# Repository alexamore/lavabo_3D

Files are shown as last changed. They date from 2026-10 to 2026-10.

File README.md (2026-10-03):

# Fontanella d'angolo per riempimento bottiglie — stampabile in 3D (ASA, Bambu Lab P2S)

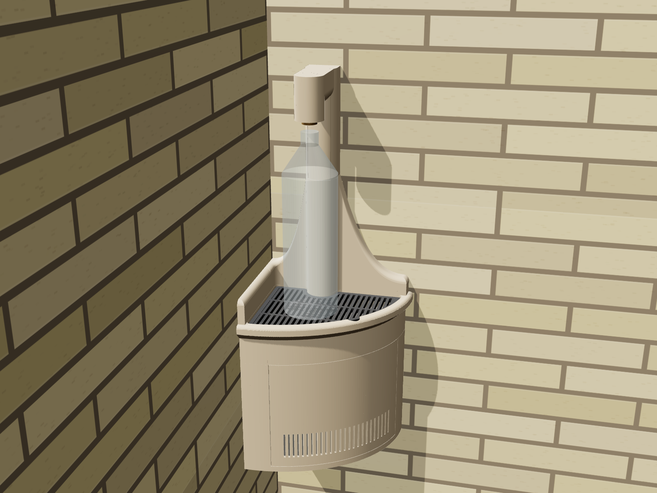
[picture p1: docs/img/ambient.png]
Vista ambientata


Piccola fontanella da esterno da fissare nell'angolo interno di due pareti in mattoni. Serve solo a
riempire bottiglie. La pianta ha **esattamente tre lati**: **250 mm** lungo la parete B, la parete
lunga su cui si fissa la fontana; **200 mm** lungo la parete A, la parete corta. Entrambi partono
dall'angolo e sono chiusi da un bordo frontale curvo e affusolato.
Il tubo PPR **esce già dal muro** della parete da 25 cm, con il centro **a 95 mm dall'angolo**
(l'angolo è a sinistra guardando la parete). Non c'è nessun tubo che arriva dal basso.
Sotto il piano c'è un vano tecnico con serbatoio estraibile, pompa sommersa 12 V, galleggianti e un
box stagno per l'ESP32.

Tutta la geometria è **parametrica** (`cad/params.py`) e viene generata da `cad/fontanella.py`.
Ogni pezzo stampato sta entro **250 × 250 × 250 mm**. Il generatore controlla da solo questo limite,
la tenuta stagna delle mesh e le interferenze tra i pezzi e con il tubo PPR.

| Elaborato | File |
|---|---|
| Tavola completa (6 viste: ambientata, pianta, prospetto, sezione, esploso, dettaglio) | [`docs/tavola_progetto.pdf`](docs/tavola_progetto.pdf) · [`.png`](docs/tavola_progetto.png) |
| Visualizzatore 3D interattivo (apri nel browser) | [`docs/viewer.html`](docs/viewer.html) |
| STL pronti per la stampa (già orientati) | [`stl/print/`](stl/print) |
| STL in posizione di montaggio | [`stl/assembly/`](stl/assembly) |
| Firmware ESP32 | [`firmware/fontanella_esp32/`](firmware/fontanella_esp32) |

| Pianta | Sezione | Dettaglio beccuccio |
|---|---|---|
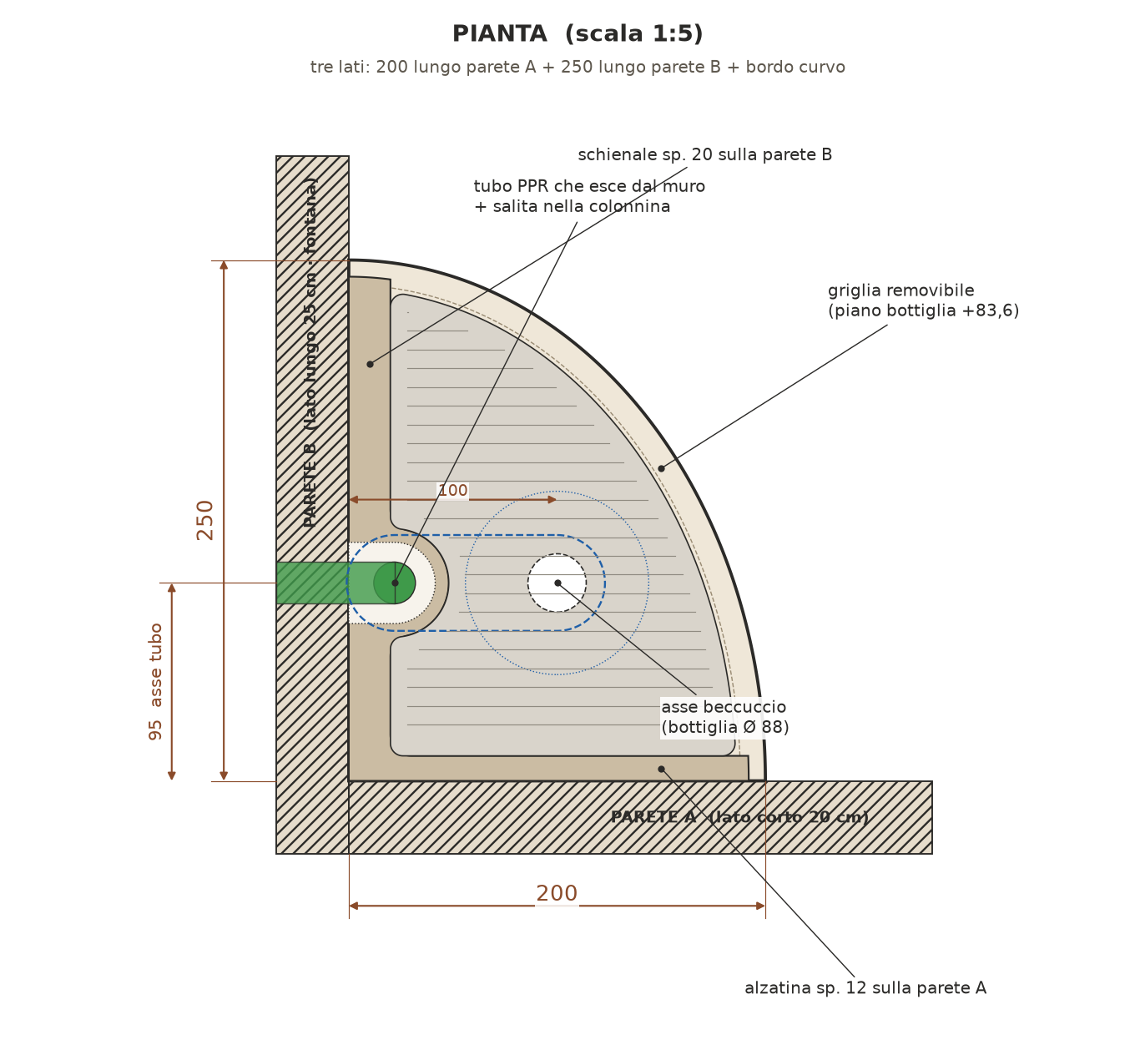
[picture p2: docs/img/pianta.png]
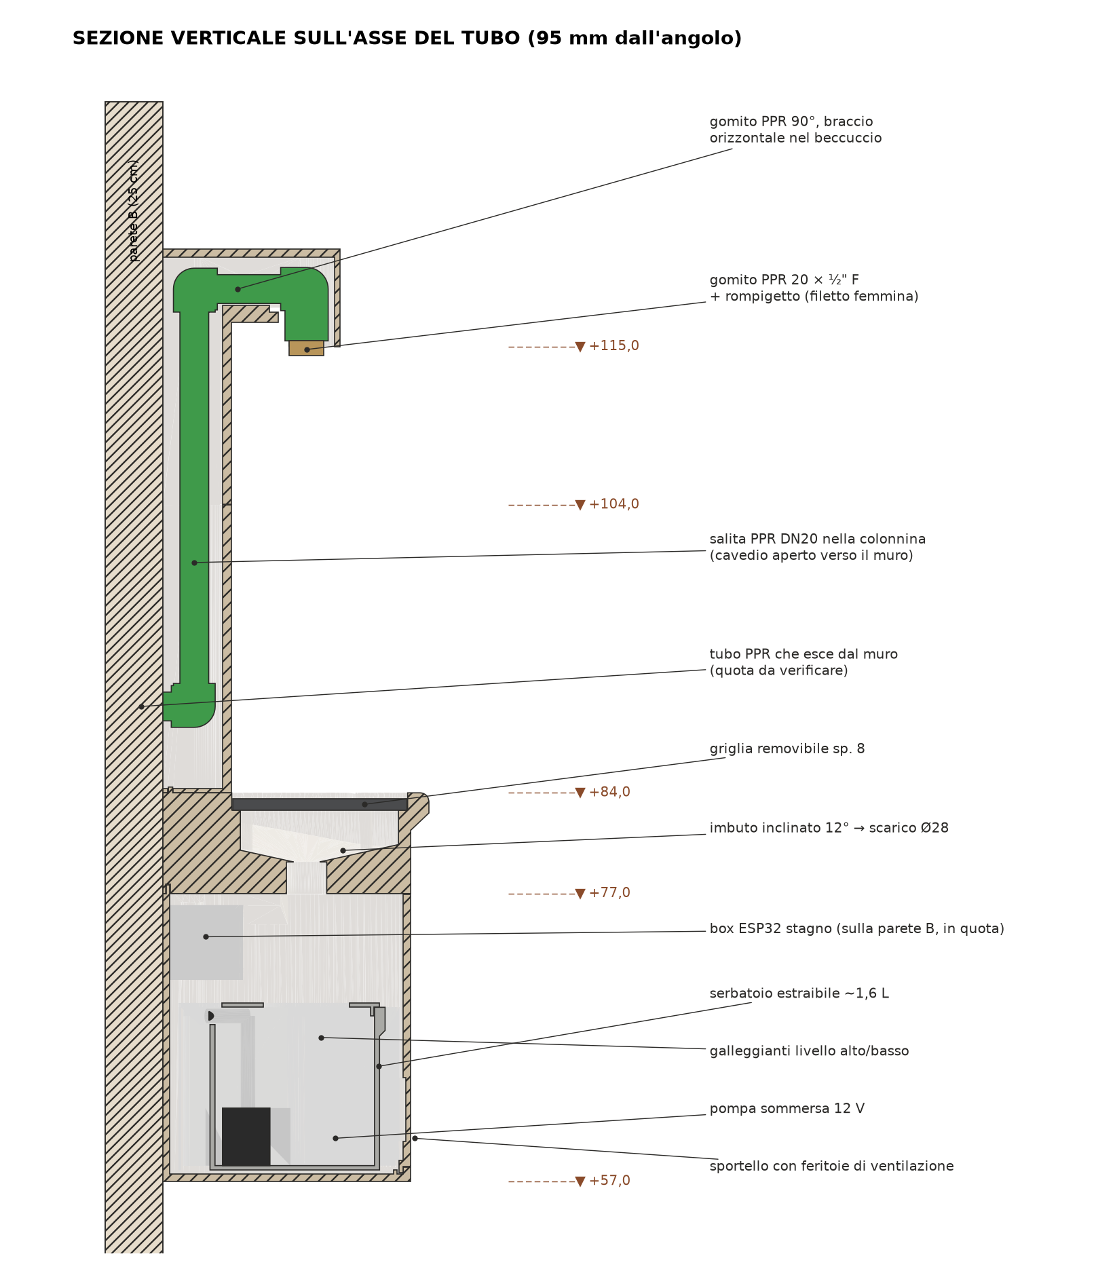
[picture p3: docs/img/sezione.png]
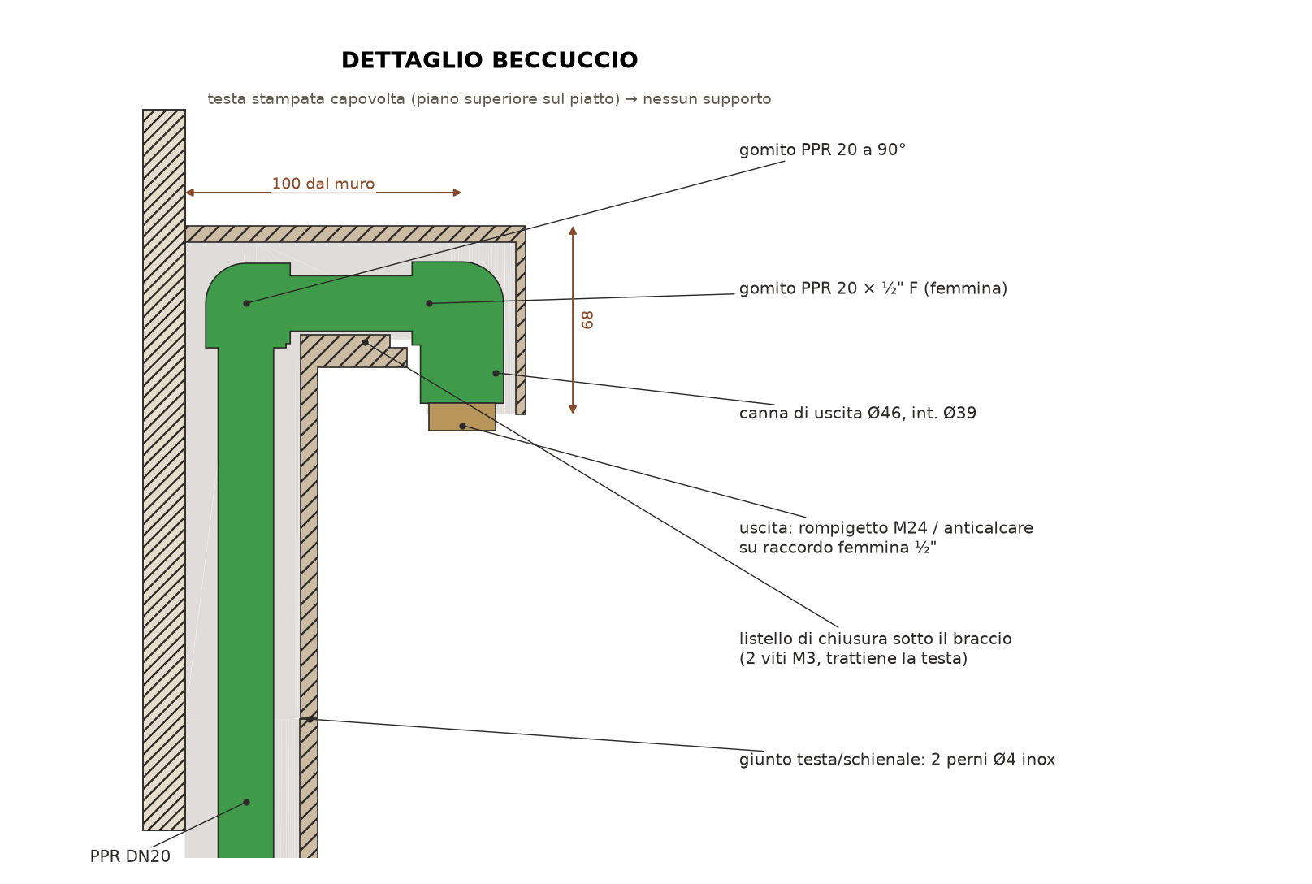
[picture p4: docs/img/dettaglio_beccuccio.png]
|  |  |  |

---

## 1. Geometria e quote

Riferimento: origine nello spigolo delle pareti, a livello del pavimento. X lungo la parete A
(corta, 20 cm), Y lungo la parete B (lunga, 25 cm, fontana), Z verso l'alto.

| Elemento | Quota |
|---|---|
| Pianta | 250 (parete B, fontana) × 200 (parete A), bordo frontale a quarto d'ellisse |
| Piano vasca (bordo) | **+840** dal pavimento |
| Piano griglia (appoggio bottiglia) | +836 |
| Uscita beccuccio | **+1150** (luce libera 314 mm sopra la griglia: entra una bottiglia da 1,5 L in piedi) |
| Asse tubo e beccuccio | **95 mm dall'angolo** lungo la parete da 25 cm; beccuccio a 100 mm dal muro |
| Uscita del tubo dal muro | +900 (**valore provvisorio, da misurare**; il modello accetta da +855 a +1130) |
| Sommità testa | +1218 |
| Vano tecnico | da +570 a +770 (appeso al muro, sotto non c'è altro) |

**Vincoli rispettati**
- La vasca aderisce alle due pareti. I due lati rettilinei partono dallo stesso spigolo e non c'è spazio tra lavabo e angolo.
- La pianta ha 3 lati: 250 (parete della fontana) + 200 + bordo curvo.
- La fontana è fissata sul lato da 25 cm, con il beccuccio in asse al tubo, a 95 mm dall'angolo.
- Nessun pezzo stampato supera 250 mm in X, Y o Z.
- Lo schienale sulla parete da 25 cm ha una colonnina sopra il tubo e profilo a onda. Nasconde
  l'uscita dal muro, la salita e le due curve. Sulla parete da 20 cm c'è solo un'alzatina paraspruzzi di 4 cm.

> Pareti assunte a **90°**.

## 2. Pezzi da stampare

| # | Pezzo | Ingombro di stampa (mm) | Colore | Orientamento |
|---|---|---|---|---|
| 01 | Vasca (piano, bordo affusolato, sede griglia, imbuto) | 200 × 250 × 74 | sabbia | diritta |
| 02 | Griglia removibile | 164 × 220 × 8 | antracite | piatta |
| 03 | Schienale (onda + colonnina sul tubo + alzatina) | 192 × 242 × 200 | sabbia | diritto |
| 04 | Testa con beccuccio | 127 × 52 × 178 | sabbia | **capovolta** (faccia superiore piatta sul piatto) |
| 05 | Listello di chiusura a L (sotto il braccio) | 52 × 37 × 138 | sabbia | capovolto |
| 06 | Corpo vano tecnico | 188 × 238 × 206 | sabbia | diritto |
| 07 | Sportello curvo con feritoie | 144 × 188 × 194 | sabbia | capovolto, in piedi |
| 08 | Serbatoio estraibile (~1,6 L) | 158 × 177 × 113 | qualsiasi | diritto |
| 09 | Coperchio serbatoio | 158 × 177 × 9 | qualsiasi | capovolto |
| 10 | Box elettronica stagno | 52 × 90 × 48 | antracite | sul dorso (apertura in alto) |
| 11 | Coperchio box | 52 × 90 × 3 | antracite | piatto |

Gli STL in `stl/print/` sono già orientati e appoggiati sul piatto. Vasca e corpo occupano fino a
250 mm sul piatto da 256 mm della P2S: centrali bene.

**Impostazioni consigliate per l'ASA su P2S**
- Ugello 0,4, layer 0,2 (0,16 per testa e listello), camera chiusa, piatto a 100 °C, ugello 255–265 °C.
- 4 perimetri (5 per vasca e serbatoio), 5 layer superiori e inferiori, infill gyroid 15 % (25 % per la testa).
- Nessun supporto. Tutte le sporgenze sono a 45° o in ponte breve. La testa va stampata capovolta.
- Per pezzi grandi (vasca, schienale, corpo) usa un brim di 5 mm e niente ventola nei primi layer, per limitare il warping dell'ASA.
- **Impermeabilizzazione**: l'ASA stampato non è stagno al 100 %. Stendi una mano di resina
  epossidica trasparente (o vernice poliuretanica bicomponente) sull'imbuto della vasca e
  dentro il serbatoio. Il resto può restare grezzo.

## 3. Materiali da acquistare

**Idraulica** (acqua potabile: solo tubo e raccordi certificati, nessun canale stampato)
- Tubo PPR DN20 PN20 per la salita e il braccio, circa 0,5 m.
- 2 gomiti PPR 20 a 90°: uno all'uscita dal muro (verso l'alto), uno in cima alla salita.
- 1 gomito PPR 20 × ½" F, cioè con filetto femmina in ottone: è il terminale del beccuccio, rivolto verso il basso.
- 1 rompigetto o anticalcare con adattatore ½" M → M24 (o M22), da avvitare nel raccordo femmina.
- Raccordi di collegamento al miscelatore esistente.

**Viteria (inox A2)**
- 4 inserti a caldo M4 + 4 viti M4×20: corpo → vasca, dalle linguette interne.
- 4 inserti a caldo M4 + 4 viti M4×25: vasca → schienale, avvitate da sotto la vasca.
- 2 inserti a caldo M3 + 2 viti M3×10 svasate: listello sotto il braccio.
- 4 inserti a caldo M3 + 4 viti M3×10: coperchio del box.
- 2 perni inox Ø4×18: giunto testa/schienale.
- 6 viti 5×60 con tasselli da 8 mm per i mattoni (corpo a muro) + 2 viti 4,5×60 con tasselli da 6 (box + corpo sulla parete da 25 cm).
- 2 magneti al neodimio 6×3 nello sportello + 2 nella vasca, sotto.
- Silicone neutro per esterni e striscia EPDM adesiva 3×6 per il coperchio del box.

**Elettronica**
- ESP32 DevKit (o ESP32-C3 SuperMini).
- Pompa sommersa 12 V DC brushless (circa 45×40×40 mm, 3–5 W) + tubo di mandata Ø 8/10.
- 2 galleggianti verticali con filetto M10: livello alto e livello basso.
- MOSFET logic-level (modulo AO3400 o IRLZ44N) + diodo 1N5819 (o 1N4007) in parallelo alla pompa.
- Convertitore buck 12 → 5 V (Mini560 o LM2596).
- Alimentatore 12 V 1 A (SELV), da tenere in casa o in contenitore IP65, con fusibile da 1 A sulla linea 12 V.
- 2 pressacavi PG7 sul fondo del box.

## 4. Sequenza di montaggio

1. **Tracciamento.** Segna l'angolo, l'asse del tubo (95 mm dall'angolo sulla parete da 25 cm) e le quote +570 (fondo del vano) e +840 (piano). Controlla la squadra delle pareti.
2. **Tubo PPR.** Il tubo esce dal muro a +900 (da adattare alla quota reale). Salda subito un gomito a 90° verso l'alto, con la salita a 22 mm dal muro. A **+1190** salda il gomito a 90° rivolto verso l'esterno, poi circa 55 mm di tubo orizzontale e il gomito 20 × ½" F rivolto verso il basso, con l'asse a 100 mm dal muro. La faccia del raccordo deve stare a circa +1154. Fai la prova di pressione **prima** di rivestire.
3. **Corpo.** Appoggialo all'angolo sotto il tubo, mettilo in bolla e fissalo con 6 viti nei mattoni, 3 per parete.
4. **Box elettronica.** Fissalo all'interno della parete da 25 cm con 2 viti passanti nel corpo e nel muro, sigillando i fori. I cavi passano nei pressacavi sul fondo del box. Mandata della pompa e cavo 12 V escono dai due fori nel fondo del vano, vicino all'angolo.
5. **Vasca + schienale.** Uniscili al banco con 3 viti M4 da sotto e un cordolo di silicone sulla cresta anti-infiltrazione. Avvicina il gruppo al muro: il tubo entra nel cavedio della colonnina, aperto verso il muro. Abbassalo sull'anello di centraggio del corpo e fissalo con 4 viti M4 dalle linguette interne.
6. **Testa.** Calala **dall'alto** sul tubo: colonnina, braccio e canna di uscita sono aperti in basso. Centrala sui 2 perni Ø4.
7. **Listello a L.** Chiude la feritoia della colonnina e il canale sotto il braccio. Si fissa con 2 viti M3 e blocca la testa sul tubo, così non si può sfilare verso l'alto.
8. **Rompigetto.** Avvitalo nel raccordo femmina ½".
9. **Silicone.** Stendi un cordolo neutro tra schienale, alzatina e mattoni.
10. **Vano tecnico.** Inserisci il serbatoio con pompa e galleggianti, poi monta griglia e sportello: aggancio in basso, magneti in alto.

**Manutenzione.** Togli lo sportello, sfila il serbatoio in diagonale (sopra ci sono 3 mm di soglia) e
puliscilo. La griglia si solleva con la tacca frontale e scopre l'imbuto per la pulizia.
Il **troppo pieno** del serbatoio scarica sul fondo del vano, che ha 6 fori di drenaggio verso il
pavimento. L'elettronica sta in quota, in un box chiuso con guarnizione e pressacavi rivolti verso il basso.

## 5. Elettronica e firmware

| Collegamento | Pin ESP32 |
|---|---|
| Galleggiante livello ALTO (contatto verso GND) | GPIO 32 |
| Galleggiante livello BASSO (contatto verso GND) | GPIO 33 |
| Gate MOSFET pompa | GPIO 25 (resistenza 100 Ω in serie, 100 kΩ verso GND) |
| LED di stato | GPIO 2 (quello sulla scheda) |
| Alimentazione | 12 V → buck 5 V → pin 5V/VIN |

Il firmware (`firmware/fontanella_esp32/fontanella_esp32.ino`, Arduino IDE) funziona così:
- avvia la pompa quando il livello alto resta attivo per più di 2 s;
- la ferma 3 s dopo che si libera il galleggiante basso, quindi non gira a secco;
- ha un tempo massimo di marcia di 60 s e una pausa minima di 10 s;
- dopo 3 cicli scaduti con il livello ancora alto va in **guasto** (pompa bloccata o tubo ostruito): LED lampeggiante e nuovo tentativo ogni 10 minuti.

Con un solo galleggiante imposta `UN_SOLO_GALLEGGIANTE = true`: la pompa gira a tempo.
La logica è stata provata con una simulazione su PC. Sulla scheda reale va verificato il verso dei galleggianti (`CONTATTO_CHIUSO_CON_ACQUA`).

## Copertura provvisoria del rubinetto esistente

Finché non si monta la fontanella, sul rubinetto doppio già installato va un cappuccio
in ASA. Il rubinetto sporge 175 mm dalla parete da 25 cm, con l'asse a 95 mm dall'angolo.

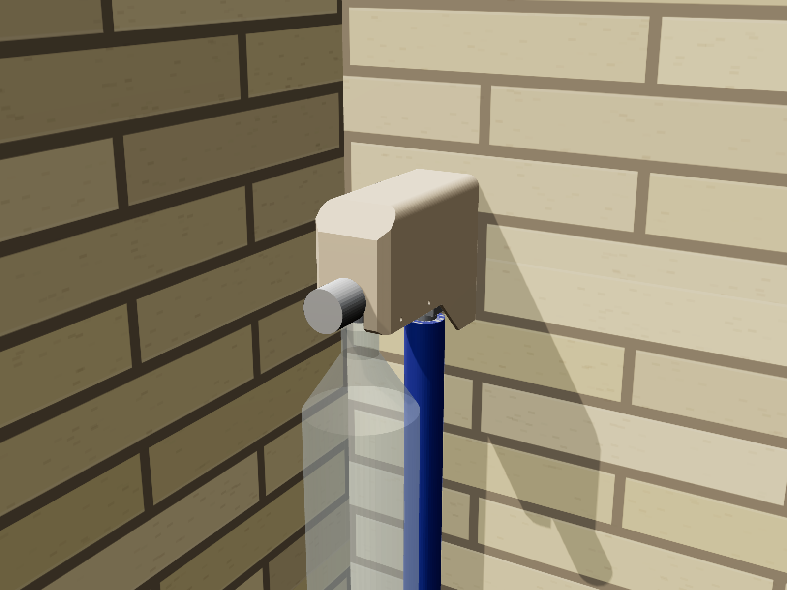
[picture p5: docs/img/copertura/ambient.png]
Copertura rubinetto


| # | Pezzo | Ingombro di stampa (mm) | Orientamento |
|---|---|---|---|
| 20 | Guscio (`stl/print/20_copertura_rubinetto.stl`) | 120 × 62 × 144 | faccia frontale sul piatto, nessun supporto |
| 21 | Fondo a scatto (`stl/print/21_fondo_copertura.stl`) | 80 × 58 × 11 | piatto |

- **Cosa copre:** gomito in ottone, comando superiore e prima uscita, fino a 143,5 mm dal muro.
- **Comando frontale:** da 145 a 175 mm resta fuori dal guscio, libero da ruotare.
- **Apertura per la bottiglia:** sul fondo, da 114 mm fino al fronte, larga 32 mm. La bottiglia si infila direttamente sull'uscita usata, a circa 128 mm dal muro.
- **Montaggio senza forare il muro:**
  1. Cala il guscio **dall'alto**: la feritoia frontale (26 mm) si appoggia sul corpo cromato.
  2. Spingi il fondo **da sotto** finché i 4 dentini scattano nei fori dei fianchi.
  3. Il fondo resta 2 mm sotto le punte delle uscite, quindi il guscio non si può più sfilare.
  4. Per smontare, premi i dentini dai fori laterali.
- **Tubo:** gomito, raccordo e tubo isolato escono dal fondo aperto della parte posteriore. I fianchi posteriori più lunghi li nascondono.
- **Misure stimate dalle foto:** prima di stampare verifica in `cad/copertura_rubinetto.py` (dizionario `TAP`):
  - altezza del comando superiore (stimata 58 mm sopra l'asse);
  - posizione delle uscite (stimate a 88 e 128 mm dal muro);
  - lunghezza delle uscite (stimata 18 mm).
- **Tavola quotata:** [`docs/tavola_copertura_rubinetto.pdf`](docs/tavola_copertura_rubinetto.pdf). **Viewer 3D:** [`docs/copertura_viewer.html`](docs/copertura_viewer.html).

```bash
python3 cad/copertura_rubinetto.py && python3 render/build_copertura.py && python3 render/drawings_copertura.py
```

## 6. Rigenerare e personalizzare

```bash
pip install manifold3d trimesh shapely numpy matplotlib
python3 cad/fontanella.py        # STL + controllo dimensioni (stl/parts.json)
python3 render/drawings.py       # tavole 2D (usa i render in docs/img)
python3 render/build_viewer.py   # docs/viewer.html
```

Parametri utili in `cad/params.py`:
- `Z_OUTLET`: altezza del beccuccio. La testa si adegua da sola.
- `Z_TOP`: altezza del piano.
- `A`, `B`: lati della pianta.
- `ARC_N`: forma del bordo frontale (2 = quarto d'ellisse, valori più alti = più "pieno").
- `PIPE_Y`: distanza del tubo dall'angolo (95).
- `Z_PIPE_IN`: quota di uscita del tubo dal muro.
- `SPOUT`: posizione del beccuccio.
- `T_W`, `T_S`, `UPSTAND_H`: spessori dello schienale, spessore e altezza dell'alzatina.
- `DOOR_A1` / `DOOR_A2`: apertura dello sportello.
- `TANK_*`: dimensioni del serbatoio.

## 7. Note e verifiche prima della realizzazione

- **Misura la quota a cui il tubo esce dal muro** e impostala in `Z_PIPE_IN`. Il modello copre da +855 a +1130. Se il tubo esce sotto il piano (+840), la vasca va forata e ripensata in quel punto.
- Verifica le misure reali dei raccordi PPR che compri. Il canale nella testa ha luce Ø38–39 mm e accoglie gomiti fino a circa Ø34.
- Il fissaggio è pensato per mattoni pieni o semipieni. Con altri supporti cambia i tasselli.
- L'impianto elettrico è **solo 12 V SELV**. L'alimentatore a 230 V va in casa o su una presa protetta da differenziale.
- Il modello non è ancora stato stampato né provato in opera. Prima del pezzo definitivo, stampa una prova veloce della testa e dell'innesto testa/schienale (pochi grammi) per controllare le tolleranze.

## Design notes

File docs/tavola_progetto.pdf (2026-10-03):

FONTANELLA D'ANGOLO PER RIEMPIMENTO BOTTIGLIE · ASA stampato 3D (Bambu Lab P2S, pezzi ≤ 250 mm)

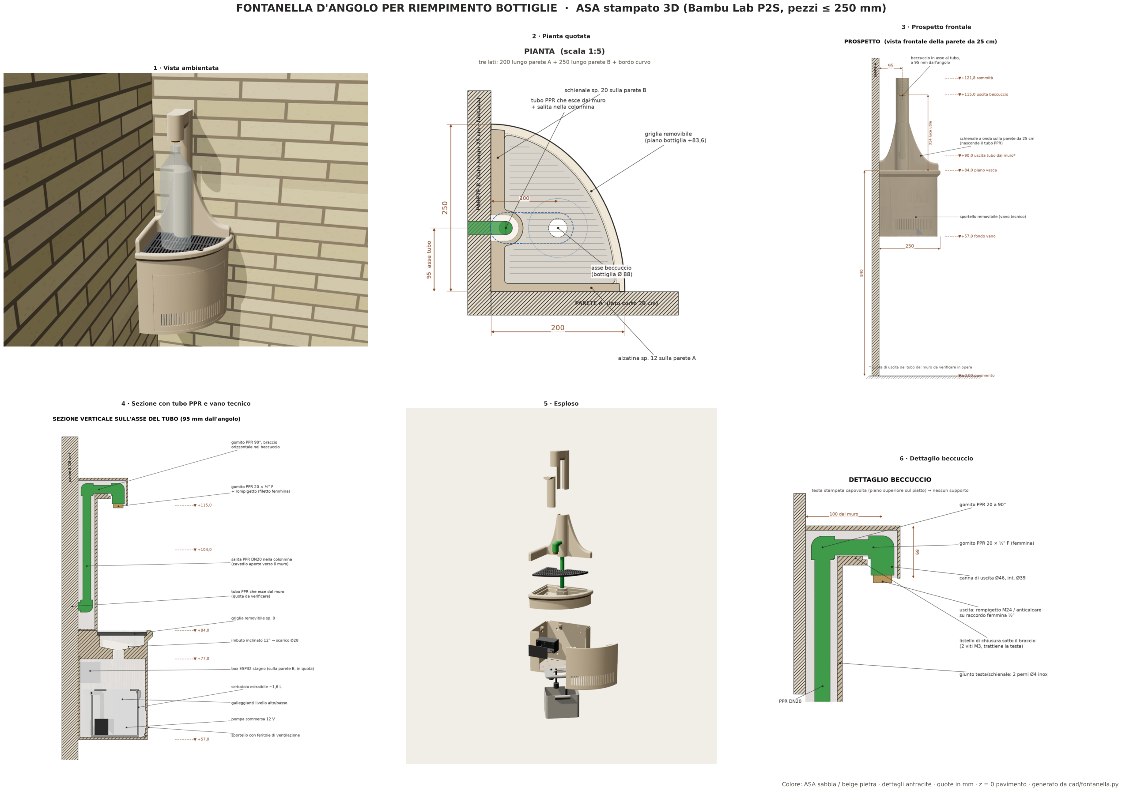
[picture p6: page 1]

1 · Vista ambientata

2 · Pianta quotata

3 · Prospetto frontale

4 · Sezione con tubo PPR e vano tecnico | 5 · Esploso

6 · Dettaglio beccuccio

Colore: ASA sabbia / beige pietra · dettagli antracite · quote in mm · z = 0 pavimento · generato da cad/fontanella.py

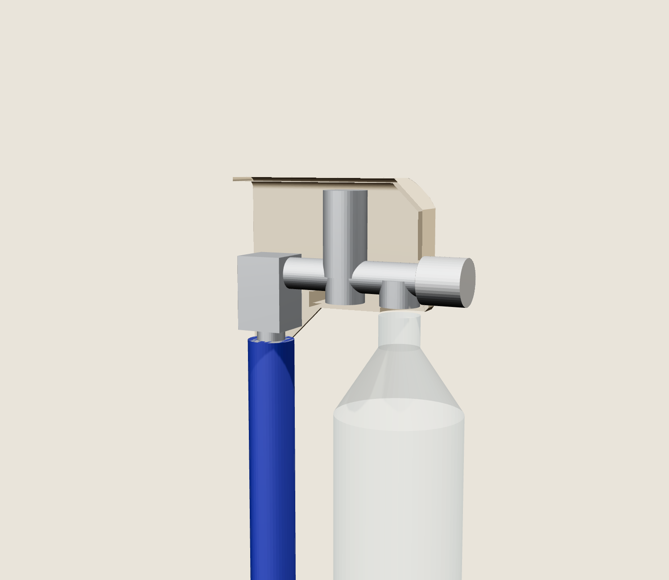
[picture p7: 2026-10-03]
docs/img/copertura/section.png

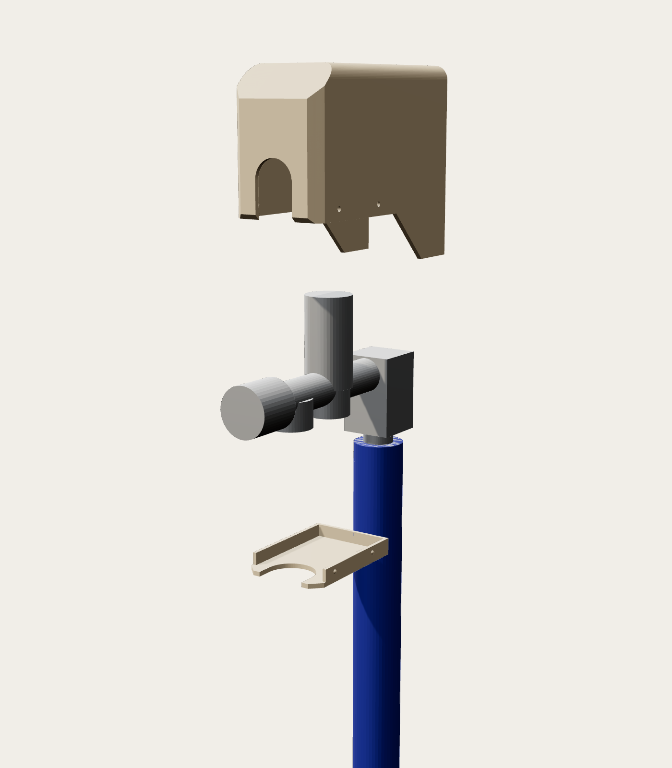
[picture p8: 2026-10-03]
docs/img/copertura/exploded.png

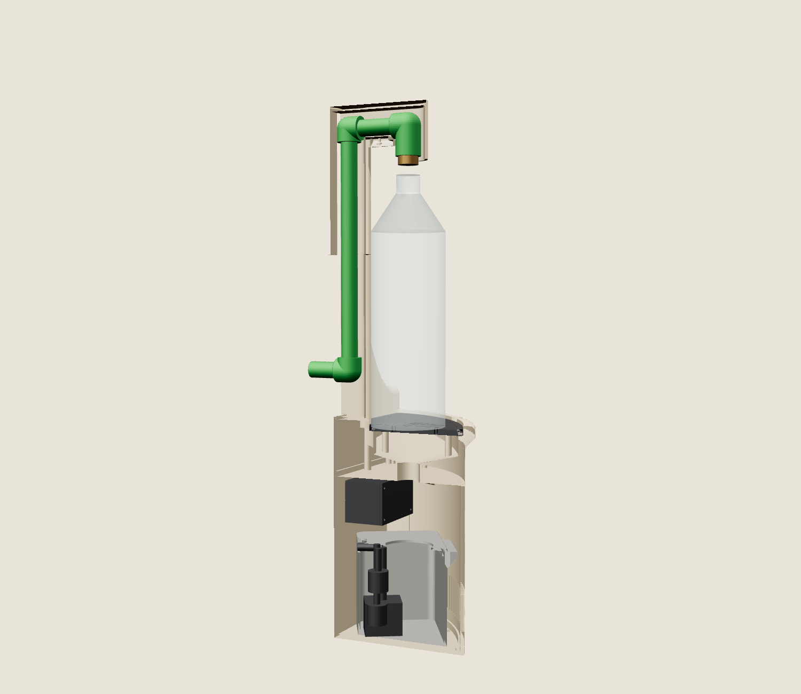
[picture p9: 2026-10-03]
docs/img/section.png

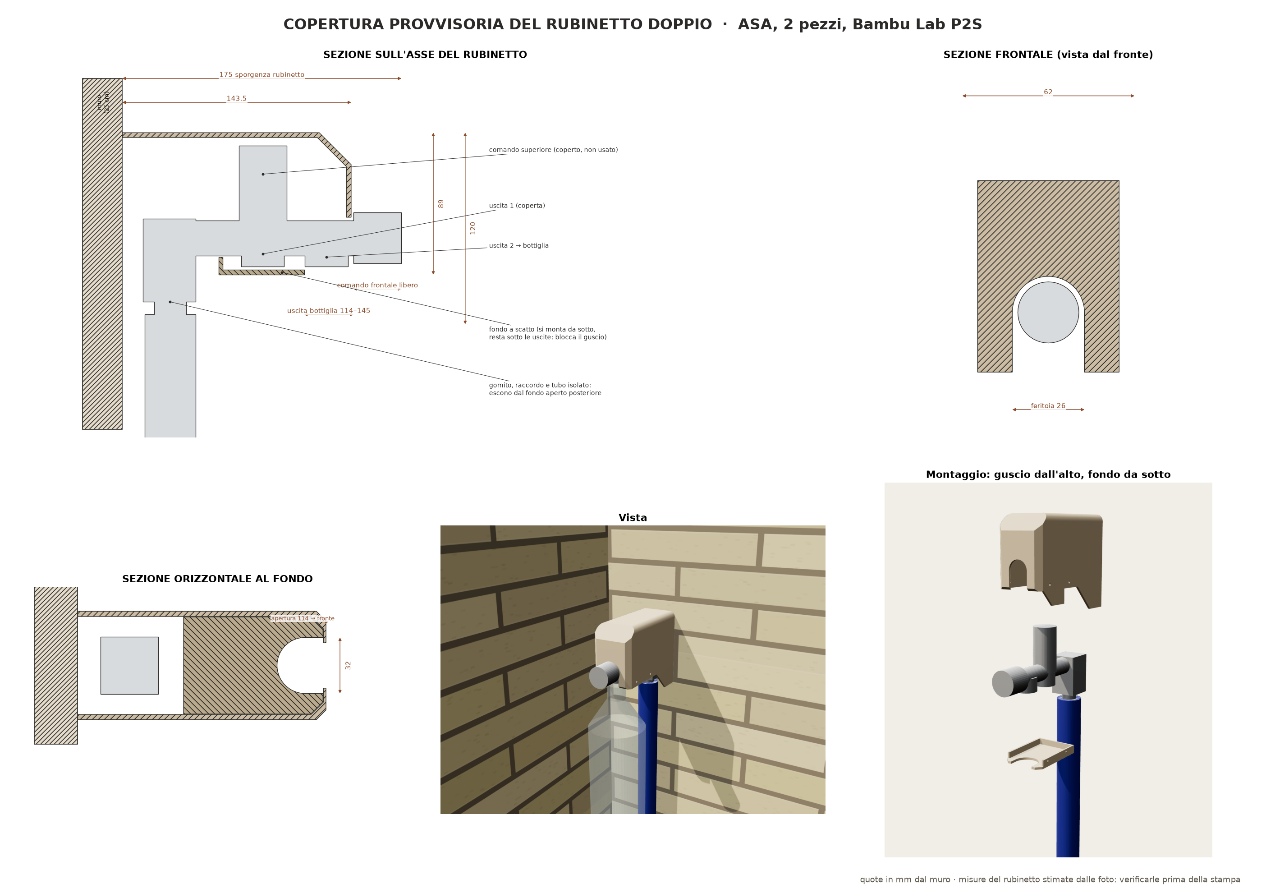
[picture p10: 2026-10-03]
docs/tavola_copertura_rubinetto.png

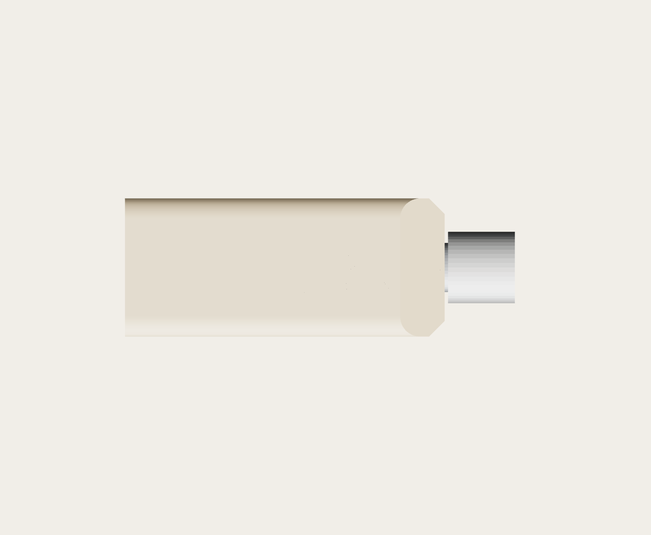
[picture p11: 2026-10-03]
docs/img/copertura/top.png

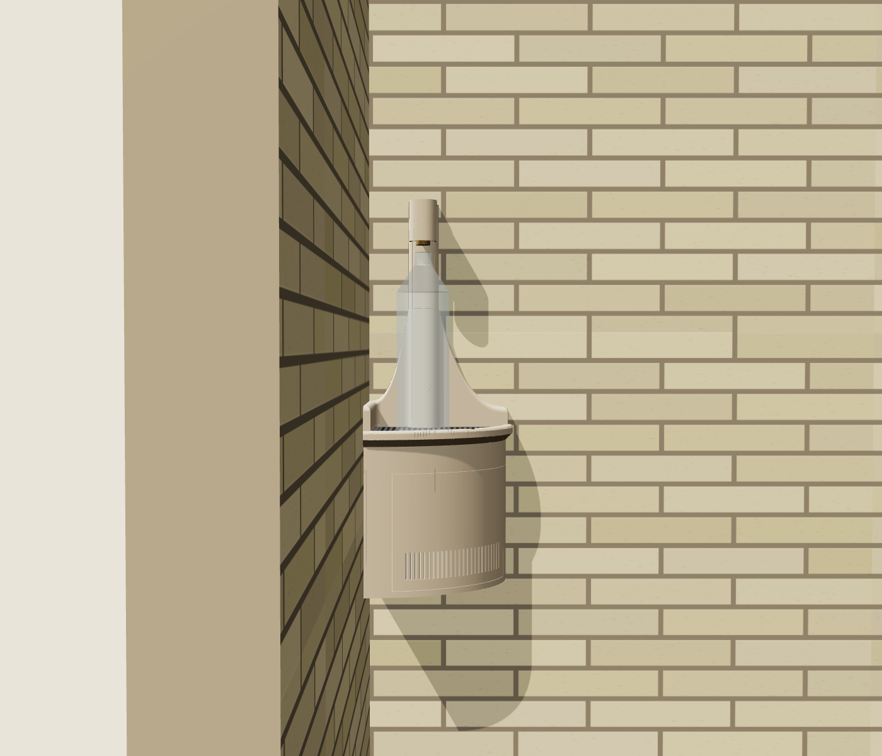
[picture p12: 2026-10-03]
docs/img/front.png

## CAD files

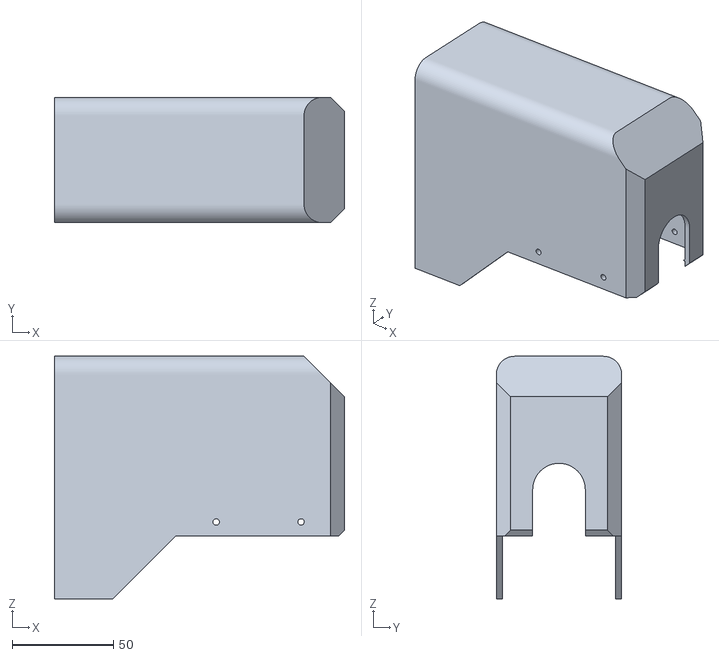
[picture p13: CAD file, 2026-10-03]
stl/assembly/20_copertura_rubinetto.stl
143.5 x 62.0 x 120.0

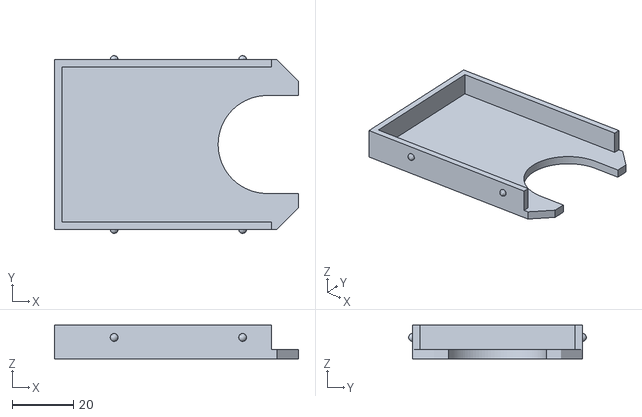
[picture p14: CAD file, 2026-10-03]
stl/print/21_fondo_copertura.stl
79.8 x 58.1 x 11.0

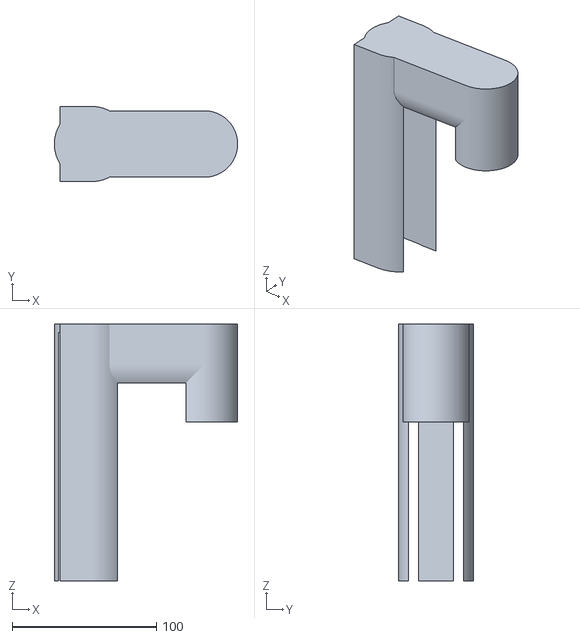
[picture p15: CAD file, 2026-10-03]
stl/assembly/04_testa_beccuccio.stl
127.0 x 52.0 x 178.0

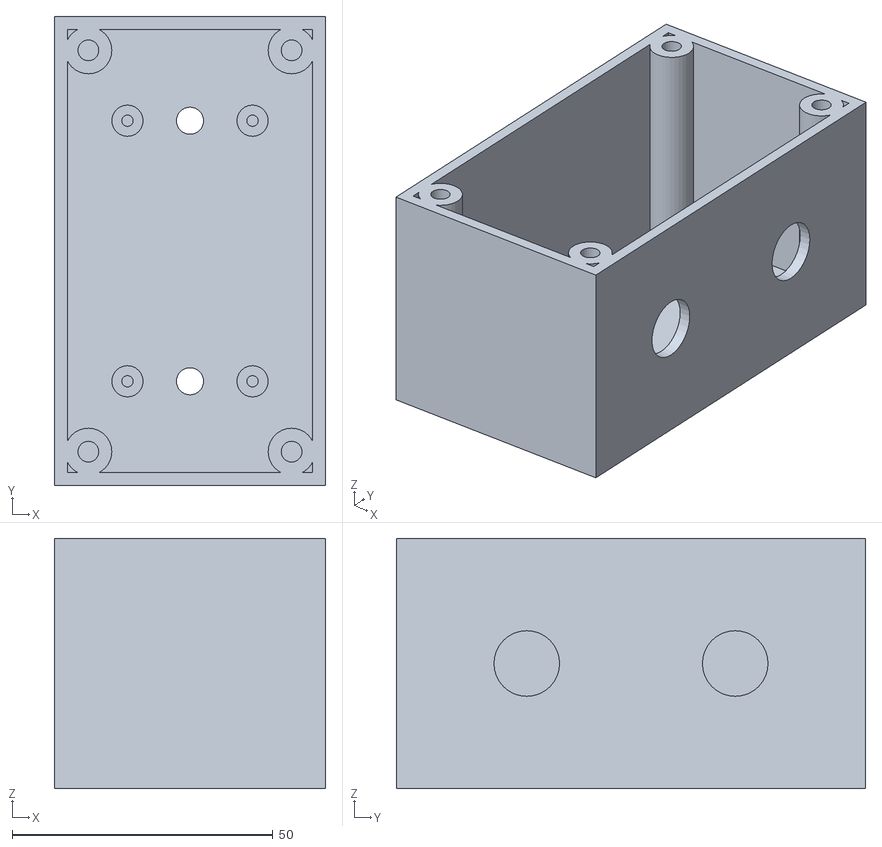
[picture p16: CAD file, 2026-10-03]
stl/print/10_box_elettronica.stl
52.0 x 90.0 x 48.0

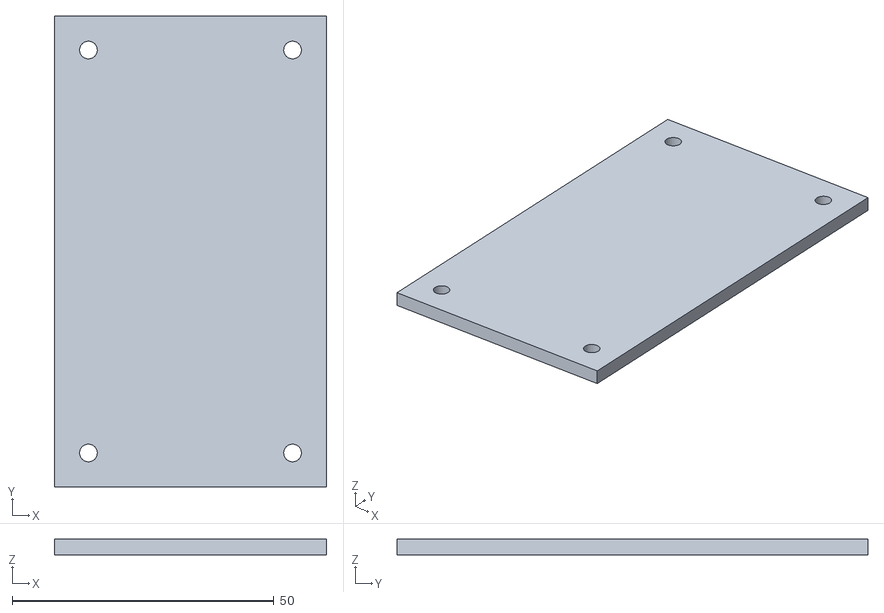
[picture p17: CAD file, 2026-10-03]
stl/print/11_coperchio_box.stl
52.0 x 90.0 x 3.00

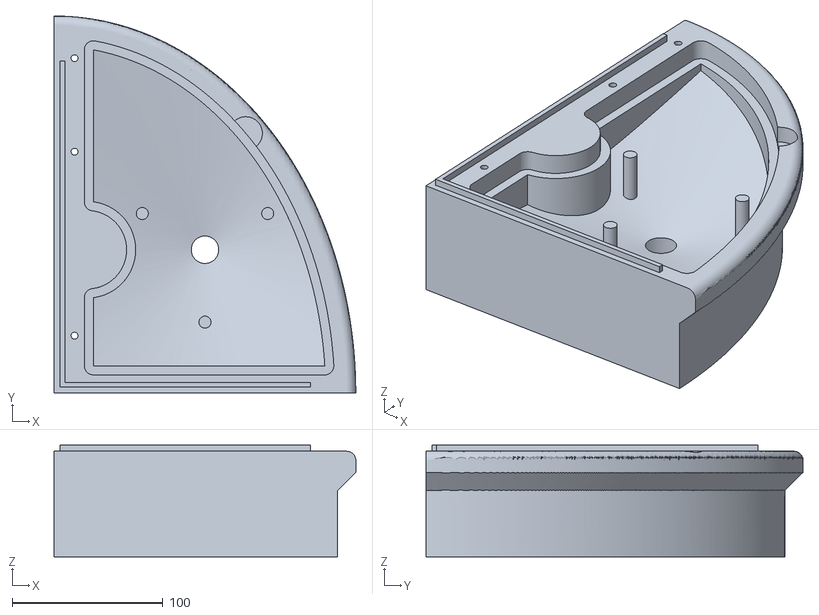
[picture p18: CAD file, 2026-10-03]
stl/assembly/01_vasca.stl
200.0 x 250.0 x 74.0

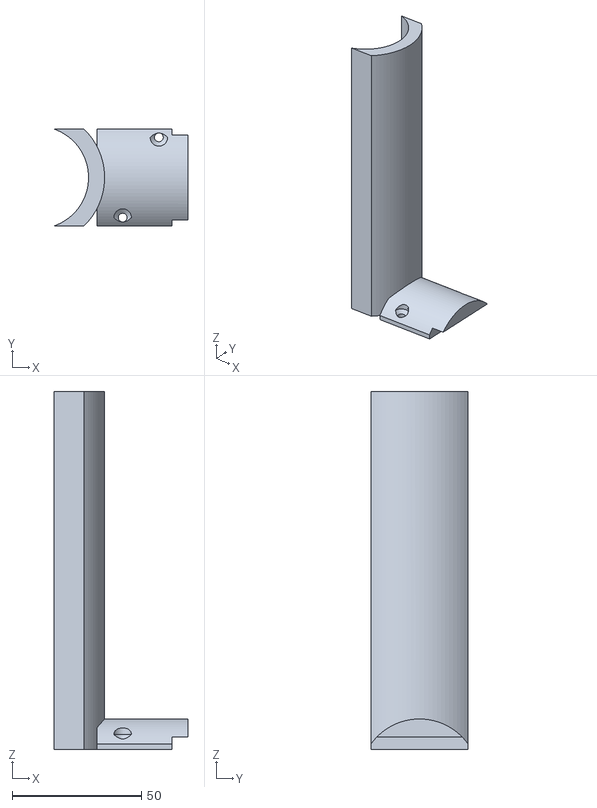
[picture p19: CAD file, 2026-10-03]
stl/print/05_copertura_braccio.stl
51.7 x 37.4 x 138.4

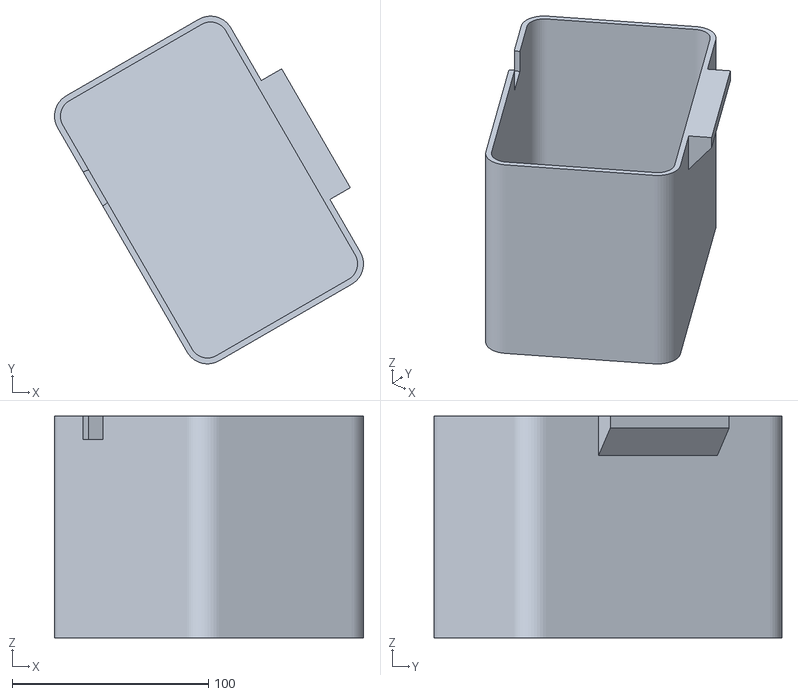
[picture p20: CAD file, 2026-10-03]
stl/print/08_serbatoio.stl
157.5 x 177.3 x 113.0

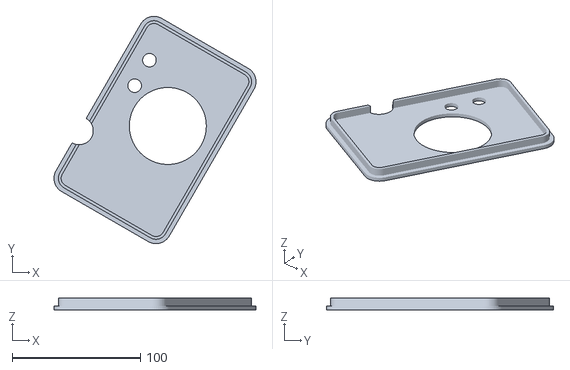
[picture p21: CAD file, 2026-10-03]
stl/print/09_coperchio_serbatoio.stl
157.5 x 177.3 x 9.00

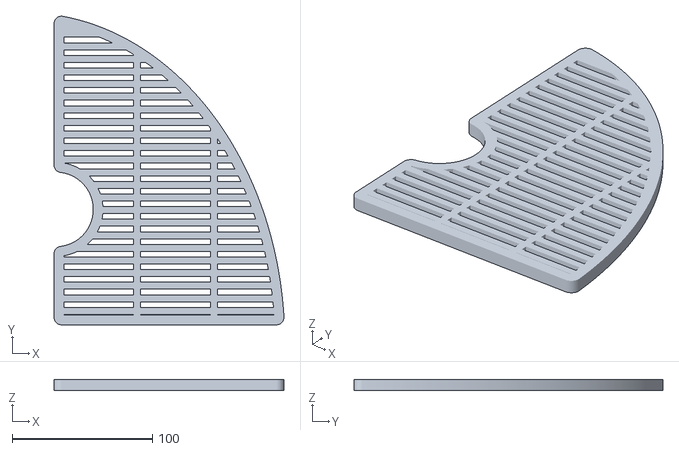
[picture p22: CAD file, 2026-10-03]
stl/assembly/02_griglia.stl
164.2 x 220.4 x 8.00

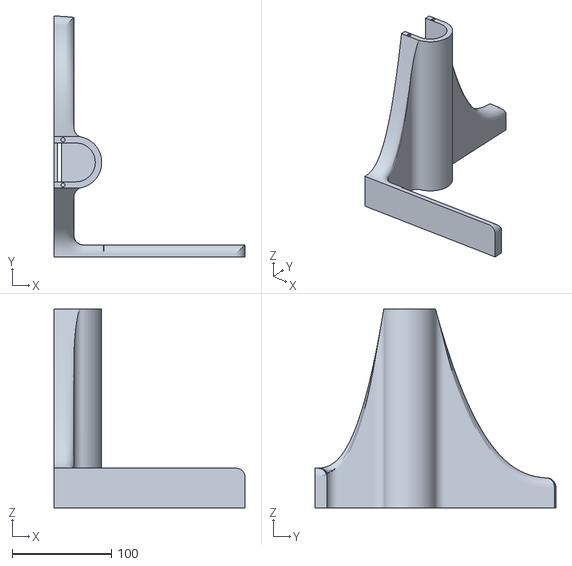
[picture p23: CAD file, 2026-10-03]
stl/print/03_schienale.stl
192.0 x 242.0 x 200.0

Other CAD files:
stl/assembly/21_fondo_copertura.stl
stl/print/20_copertura_rubinetto.stl
stl/assembly/10_box_elettronica.stl
stl/assembly/11_coperchio_box.stl
stl/assembly/08_serbatoio.stl
stl/print/01_vasca.stl
stl/assembly/05_copertura_braccio.stl
stl/assembly/03_schienale.stl
stl/assembly/06_corpo_vano.stl
stl/assembly/07_sportello.stl
stl/assembly/09_coperchio_serbatoio.stl
stl/print/02_griglia.stl
stl/print/04_testa_beccuccio.stl
stl/print/06_corpo_vano.stl
stl/print/07_sportello.stl

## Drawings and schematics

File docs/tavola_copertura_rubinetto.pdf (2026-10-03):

## COPERTURA PROVVISORIA DEL RUBINETTO DOPPIO · ASA, 2 pezzi, Bambu Lab P2S

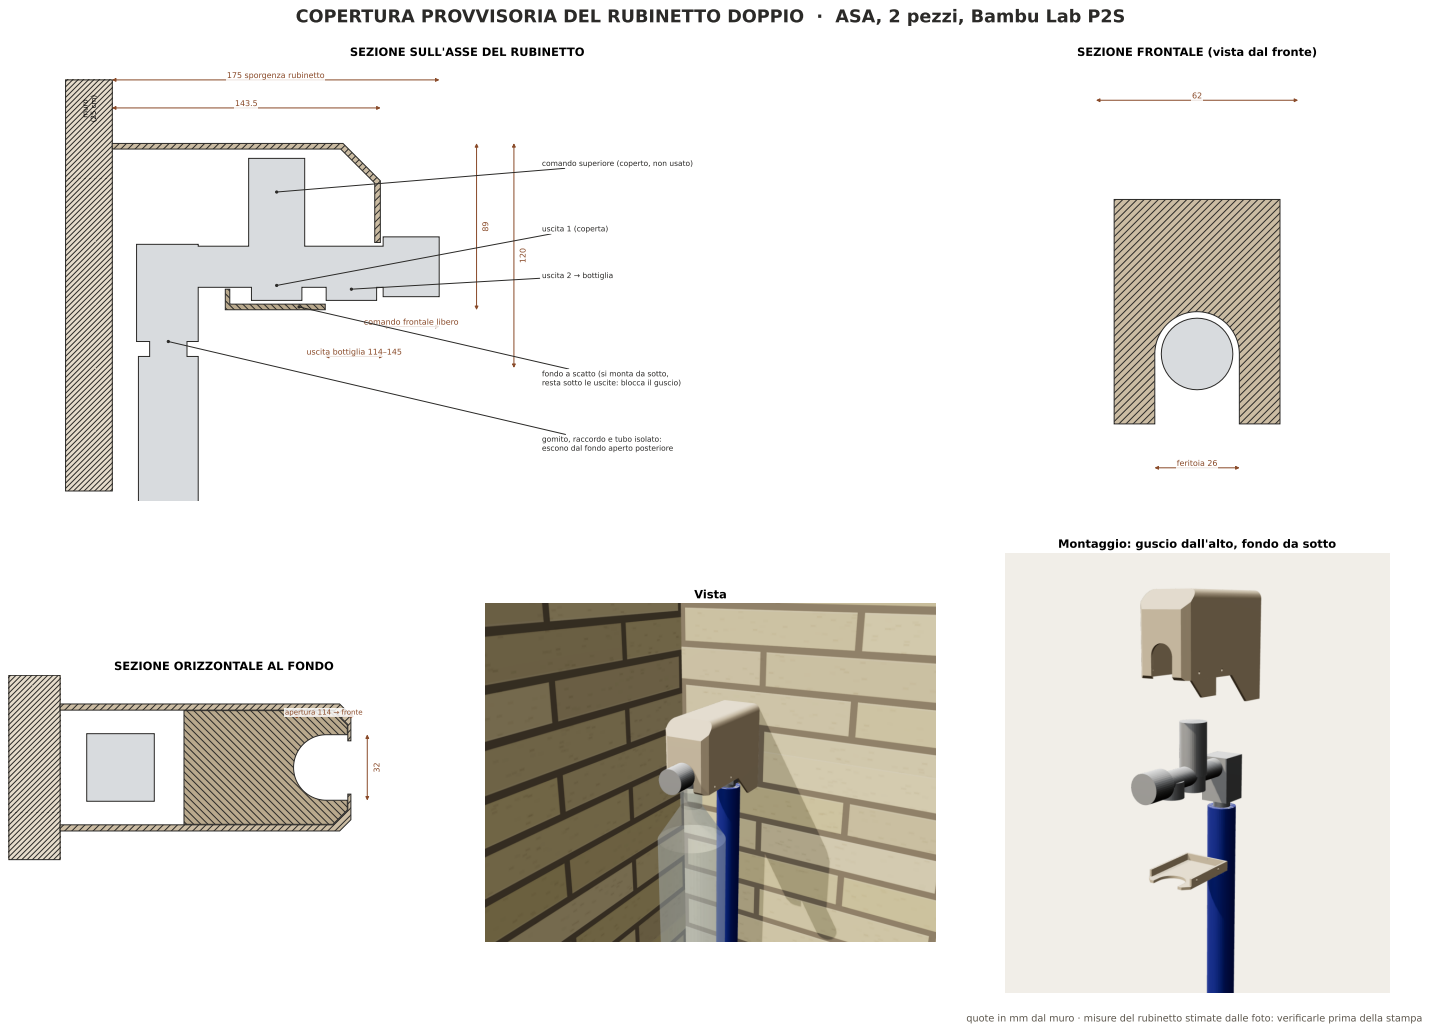
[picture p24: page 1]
muro; 175 sporgenza rubinetto; uscita bottiglia 114–145; uscita 1 (coperta); uscita 2 → bottiglia; feritoia 26; apertura 114 → fronte; Vista

SEZIONE SULL'ASSE DEL RUBINETTO

SEZIONE FRONTALE (vista dal fronte)

comando superiore (coperto, non usato)

comando frontale libero

fondo a scatto (si monta da sotto,
resta sotto le uscite: blocca il guscio)

gomito, raccordo e tubo isolato:
escono dal fondo aperto posteriore

Montaggio: guscio dall'alto, fondo da sotto

SEZIONE ORIZZONTALE AL FONDO

quote in mm dal muro · misure del rubinetto stimate dalle foto: verificarle prima della stampa

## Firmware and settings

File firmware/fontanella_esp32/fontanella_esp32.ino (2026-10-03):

/*
  Fontanella d'angolo - controllo pompa di svuotamento serbatoio
  Scheda: ESP32 DevKit (Arduino core 2.x / 3.x)

  Ingressi:
    GALL_ALTO  (GPIO 32) - galleggiante livello alto  -> avvia la pompa
    GALL_BASSO (GPIO 33) - galleggiante livello basso -> ferma la pompa (protezione marcia a secco)
    I galleggianti sono contatti verso GND, con pull-up interno.
  Uscite:
    POMPA (GPIO 25) - gate MOSFET logic-level (es. IRLZ44N / modulo AO3400), diodo di ricircolo sulla pompa
    LED   (GPIO 2)  - stato: fisso = pompa in marcia, lampeggio lento = ok, lampeggio rapido = guasto

  Logica:
    - livello alto attivo per > DEBOUNCE_MS  -> pompa ON
    - pompa OFF quando il livello basso si libera (+ RUN_ON_MS), oppure dopo MAX_RUN_MS (sicurezza)
    - pausa minima MIN_OFF_MS tra due cicli
    - se il livello alto resta attivo dopo MAX_FAULTS cicli consecutivi a tempo scaduto -> GUASTO
      (pompa bloccata / tubo ostruito): pompa ferma, nuovo tentativo ogni FAULT_RETRY_MS
    - con un solo galleggiante (UN_SOLO_GALLEGGIANTE = true) la pompa gira per TIMED_RUN_MS
*/

#include <Arduino.h>

// ---- configurazione --------------------------------------------------------
const bool UN_SOLO_GALLEGGIANTE = false;
const bool CONTATTO_CHIUSO_CON_ACQUA = true;   // inverti se il galleggiante e' montato capovolto

const int PIN_GALL_ALTO  = 32;
const int PIN_GALL_BASSO = 33;
const int PIN_POMPA      = 25;
const int PIN_LED        = 2;

const uint32_t DEBOUNCE_MS     = 2000;
const uint32_t RUN_ON_MS       = 3000;
const uint32_t MAX_RUN_MS      = 60000;
const uint32_t TIMED_RUN_MS    = 15000;
const uint32_t MIN_OFF_MS      = 10000;
const uint32_t FAULT_RETRY_MS  = 10UL * 60UL * 1000UL;
const int      MAX_FAULTS      = 3;

// ---- stato -----------------------------------------------------------------
enum Stato { ATTESA, MARCIA, RITARDO_STOP, PAUSA, GUASTO };
Stato stato = ATTESA;
uint32_t tStato = 0, tAltoDa = 0, tBassoLiberoDa = 0;
int cicliTimeout = 0;

bool acqua(int pin) {
  bool chiuso = digitalRead(pin) == LOW;
  return CONTATTO_CHIUSO_CON_ACQUA ? chiuso : !chiuso;
}

void pompa(bool on) {
  digitalWrite(PIN_POMPA, on ? HIGH : LOW);
}

void vai(Stato s) {
  stato = s;
  tStato = millis();
  pompa(s == MARCIA || s == RITARDO_STOP);
  static const char* nomi[] = {"ATTESA", "MARCIA", "RITARDO_STOP", "PAUSA", "GUASTO"};
  Serial.printf("[%lu s] stato -> %s\n", millis() / 1000, nomi[s]);
}

void setup() {
  Serial.begin(115200);
  pinMode(PIN_GALL_ALTO, INPUT_PULLUP);
  pinMode(PIN_GALL_BASSO, INPUT_PULLUP);
  pinMode(PIN_POMPA, OUTPUT);
  pinMode(PIN_LED, OUTPUT);
  pompa(false);
  vai(ATTESA);
}

void loop() {
  const uint32_t now = millis();
  const bool alto = acqua(PIN_GALL_ALTO);
  const bool basso = UN_SOLO_GALLEGGIANTE ? true : acqua(PIN_GALL_BASSO);

  // debounce livello alto
  if (alto) { if (!tAltoDa) tAltoDa = now; } else tAltoDa = 0;
  const bool altoStabile = tAltoDa && (now - tAltoDa >= DEBOUNCE_MS);

  switch (stato) {
    case ATTESA:
      if (altoStabile && basso) vai(MARCIA);
      break;

    case MARCIA: {
      const uint32_t t = now - tStato;
      if (UN_SOLO_GALLEGGIANTE) {
        if (t >= TIMED_RUN_MS) { cicliTimeout = alto ? cicliTimeout + 1 : 0; vai(cicliTimeout >= MAX_FAULTS ? GUASTO : PAUSA); }
      } else if (!basso) {
        vai(RITARDO_STOP);                       // acqua sotto il livello basso: ancora qualche secondo
      } else if (t >= MAX_RUN_MS) {
        cicliTimeout++;
        vai(cicliTimeout >= MAX_FAULTS ? GUASTO : PAUSA);
      }
      break;
    }

    case RITARDO_STOP:
      if (now - tStato >= RUN_ON_MS) { cicliTimeout = 0; vai(PAUSA); }
      break;

    case PAUSA:
      if (now - tStato >= MIN_OFF_MS) vai(ATTESA);
      break;

    case GUASTO:
      if (now - tStato >= FAULT_RETRY_MS) { cicliTimeout = MAX_FAULTS - 1; vai(ATTESA); }
      break;
  }

  // LED di stato
  bool led;
  if (stato == MARCIA || stato == RITARDO_STOP) led = true;
  else if (stato == GUASTO) led = (now / 150) % 2;
  else led = (now % 2000) < 80;
  digitalWrite(PIN_LED, led);

  delay(20);
}

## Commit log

2026-10-03 Fontanella d'angolo stampabile 3D: CAD parametrico, STL, tavole, viewer 3D, firmware ESP32
    Claude-Session: https://claude.ai/code/session_019E8bei9Cq3afdhbCJHToNx
    [01_vasca.stl, 02_griglia.stl, 03_schienale.stl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]
2026-10-03 Lato da 25 cm sulla parete della fontana, tubo a 95 mm dall'angolo che esce dal muro
    - invertiti i lati: 250 mm lungo la parete B (fontana), 200 mm lungo la parete A
    - schienale solo sulla parete lunga, con colonnina sul tubo e profilo a onda; alzatina sulla parete corta
    - tubo PPR che esce dal muro (quota parametrica Z_PIPE_IN), beccuccio in asse a 95 mm dall'angolo
    - eliminati cavedio d'angolo e copritubo inferiore; corpo, serbatoio e box riposizionati
    - tavole, render, viewer e README aggiornati
    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
    [01_vasca.stl, 02_griglia.stl, 03_schienale.stl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]
2026-10-03 Box elettronica: orientamento di stampa con apertura verso l'alto
    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
    [10_box_elettronica.stl, 11_coperchio_box.stl]
2026-10-03 Copertura provvisoria per il rubinetto doppio esistente
    - guscio ASA calato dall'alto sul rubinetto (feritoia sul corpo cromato), comando frontale libero
    - fondo a scatto da sotto con apertura per la bottiglia da 114 mm al fronte; blocca il guscio
    - tavola quotata, render e viewer 3D dedicati; verifiche di interferenza e di montaggio
    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
    [20_copertura_rubinetto.stl, 21_fondo_copertura.stl]
